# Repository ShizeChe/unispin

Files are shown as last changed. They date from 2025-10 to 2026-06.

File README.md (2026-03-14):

<h1 align="center">Unispin</h1>
<p align="center">A unified quantum control platform for quantum dot spin qubits</p>

<p align="center">
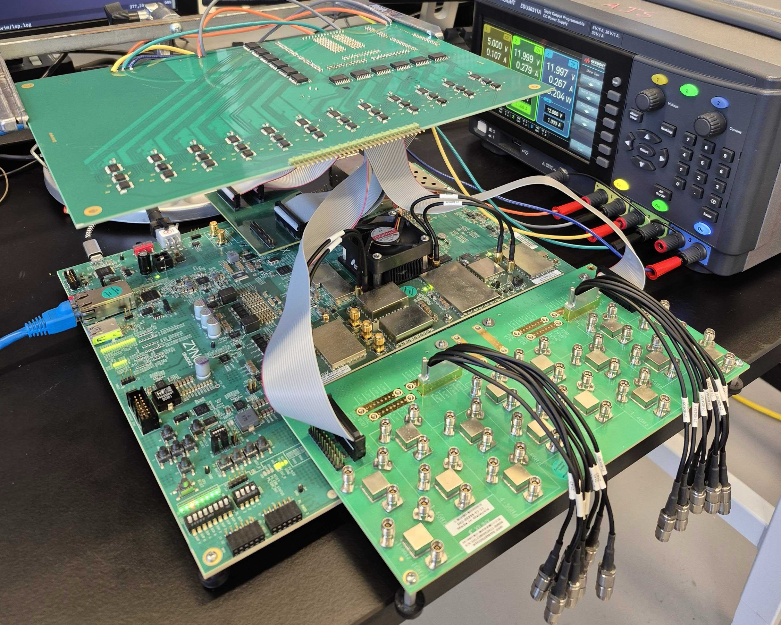
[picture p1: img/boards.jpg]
boards
 
</p>

Overview
========
Unispin is a unified quantum control platform designed specifically for quantum dot spin qubits. Its goal is to reduce control stack complexity and cost while improving performance by integrating all the requried control resources onto a single FPGA. With the two custom PCBs (FMC breakout board and low-noise DAC board), the current configuration has:

* 24x bias DC channels (AD5791BRUZ)
* 6x RF IQ pairs for further analog upconversion
* 2x singled-ended RF channels and 2x ADC channels for lockin-in measurement
* 2x singled-ended fast DC channels

Each signal and measurement channel has its own dedicated, fully-pipelined control core. Each core can be programmed to iteratively executes a sequence of custom assembly instructions with cycle-precise timing. The annotated pulse experiment assembly program and waveform below demonstrates this execution model.

```text
.program rf0                 # program for RF channel 0
.fnco 10MHz                  # NCO is 10MHz
.repeat 100                  # repeats 100 times
    idl t=19us (arm)         # idle for 19us
    ply phs=0 t=12ns (t+8ns) # play the NCO tone for 12ns (increment the pulse duration by 8ns every iteration)
    idl t=12us               # idle for 12us

.program dc0                 # program for DC channel 0
.repeat 100                  # this program repeats 100 times
    lvl v=0 t=2us (arm)      # output 0V for 2us
    lvl v=1 t=15us           # output 1V for 15us
    lvl v=2 t=2us            # output 2V for 2us
    idl t=12ns (t+8ns)       # idle for 12ns (increment the idle duration by 8ns every iteration)
    lvl v=1 t=10us           # output 1V for 10us
    lvl v=0 t=2us            # output 0V for 2us

.program li0                 # program for LI (lock-in) channel 0
.repeat 100                  # this program repeats 100 times
    idl t=19us (arm)         # idle for 19us
    idl t=12ns (t+8ns)       # idle for 12ns (increment the idle duration by 8ns every iteration)
    sam n=1000 t=10us        # sample 1000 samples spanning 10us
    idl t=2us                # idle for 2us

.launch rf0 dc0 li0          # launch RF channel 0, DC channel 0, LI channel 0 
```

<p align="center"> 
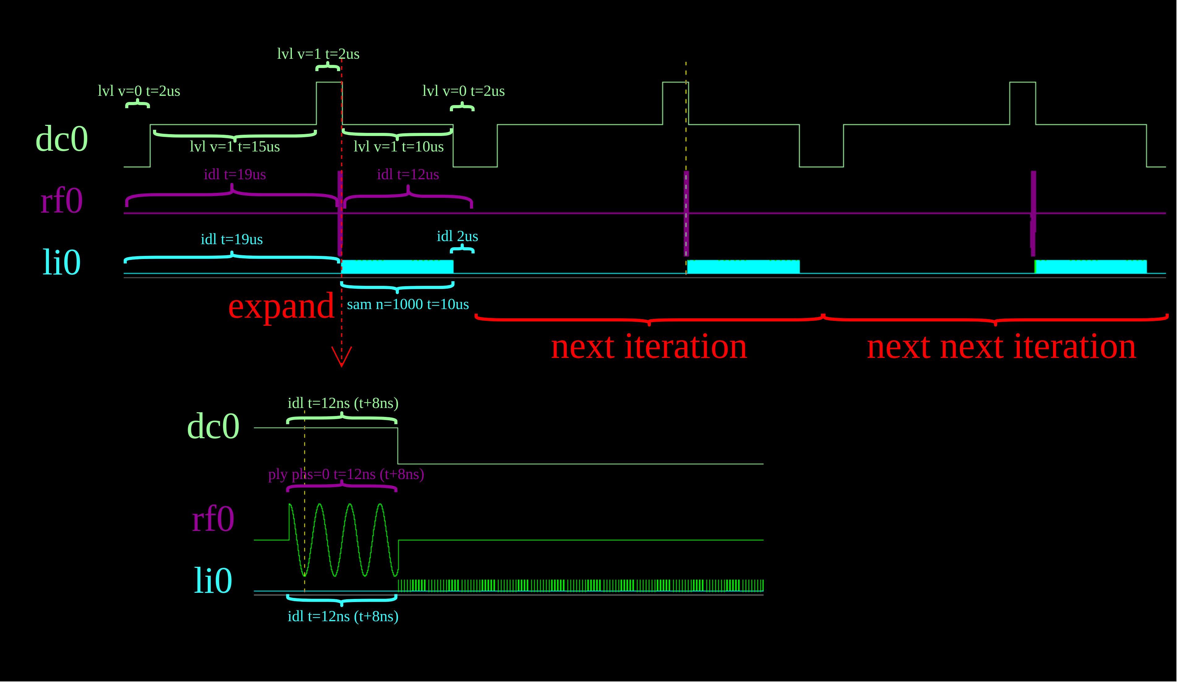
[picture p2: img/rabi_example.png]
rabi example
  
</p>

## Project Status
The project currently has three parts:
* RTL design, along with testbenches and some formal properties used for verification (under rtl)
* PCB design for the 24 bias DC channels, along with assembly instrctions (under pcb)
* Assembler for compiling and executing the custom assembly programs (under asm)

This project is currently under active development. The RTL design, PCB design, and assembler may continue to evolve as functionality is validated experimentally and the system is further refined. More detailed documentation and user guides will be added after real-device experiments.

## Building the rtl design project and bistream in Vivado
```bash
# clone repo
git clone "repo-url"

# go to the synthesis folder
cd unispin/rtl/synth

# build in vivado
vivado -script proj.tcl &
```
Note that proj.tcl only builds the project. Click generate bitstream in vivado to build the bitstream.

## Building the simulator (requires VCS+Verdi)
This simulator is our go-to method to visualize the full-system waveforms. It incorporates all the channels and cores and have simulated DAC and ADC modules for directly visualizing analog waveforms. It simulates AXI memory operations by accepting address and data through a socket interface, the received address and data are then written to the sequencer through its AXI interface.

Build the simulator. 
```bash
# assume we are in the top level of the cloned repo

# go to the rtl folder
cd unispin/rtl

# build the simulator (requires VCS)
make
```
This will create a simulator executable under rtl.

Execute the simulator in Verdi.
```bash
./simulator -gui -do sim/wv.tcl &
```

This will open up Verdi and load the waveforms. It will listen for connections and read address and data once running. Verdi can stop it at anytime to examine waveforms.

## Building the assembler
```bash
# assume we are in the top level of the cloned repo

# go to the asm folder
cd asm

# build the assmebler
make
```
This will create an executable named "squish" under asm.

Example assembling a .asm file and send to the simulator to visualize exection (with simulator running).
```bash
./squish -s -f ../exp/hahn_echo.asm
```

## Petalinux
A Petalinux OS can be built to interface with the cores in FPGA. os/petalinux-steps.md describes the steps we took to build a bootable image with an uio driver for each core.

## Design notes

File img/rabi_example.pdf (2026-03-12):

dc0

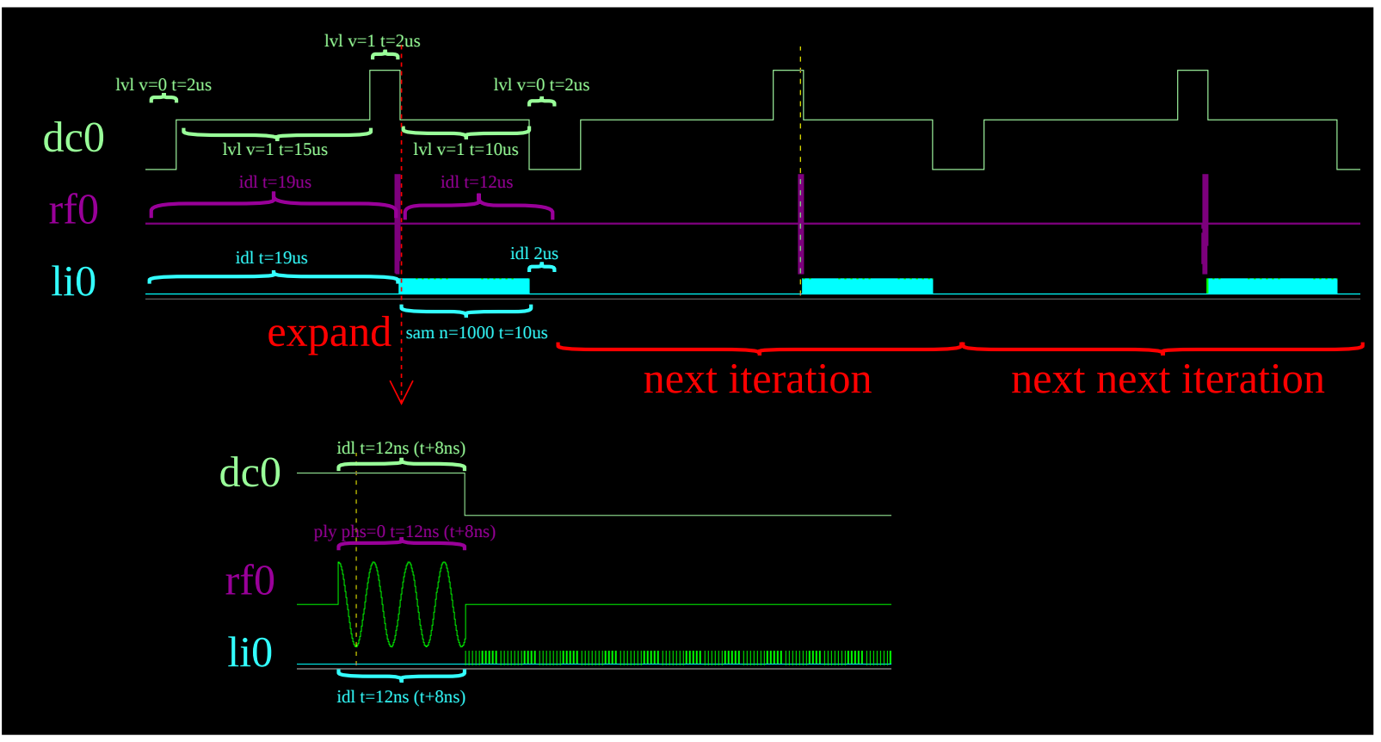
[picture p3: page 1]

rf0
li0

lvl v=0 t=2us

lvl v=1 t=15us

lvl v=1 t=2us

lvl v=1 t=10us

lvl v=0 t=2us

# expand

dc0

rf0
li0
idl t=19us | idl t=12us

idl t=12ns (t+8ns)

ply phs=0 t=12ns (t+8ns)

idl t=12ns (t+8ns)

idl t=19us

sam n=1000 t=10us

idl 2us

# next iteration next next iteration

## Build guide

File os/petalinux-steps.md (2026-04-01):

1. Export xsa file from vivado
2. Use vitis to create a linux platform with the exported xsa file as input
3. Vitis will create a folder: [vitis platform dir]/hw/sdt, this folder will be used in 7. Inside this folder, there should be a pl.dtsi file, it will be used in 13
4. Source settings.sh in the directory where petalinux is installed
5. Download the bsp (board support package) from the petalinux download page from xilinx
6. Run "petalinux-create -t project -s /path/to/bsp" to create a petalinux project directory based on the bsp
7. Run "petalinux-config --get-hw-description /path/to/[vitis platform dir]/hw/sdt" to do basic configuration
8. A terminal gui opens up, do the following:
   --DTG Settings->Kernel Bootargs->Uncheck "generate bookargs automatically"->
     Put "earlycon console=ttyPS0,115200 clk_ignore_unused uio_pdrv_genirq.of_id=generic-uio root=/dev/mmcblk0p2 rw rootwait" as the bootarg
   --FPGA Manager->Check FPGA Manager
   --Image Packaging Configurations->Root filesystem type->Select EXT4 (SD/eMMC/SATA/USB).
     Additionally, uncheck "Copy final images to tftpboot"
9. Run "petalinux-config -c kernel" to configure kernel
10. A terminal gui opens in a new shell window, check the following settings:
    --Device Drivers->Userspace I/O drivers->
      Change "Userspace I/O platform driver with generic IRQ handling" and 
      "Userspace platform driver with generic irq and dynamic memo" from "M" to fully selected
11. Run "petalinux-config -c rootfs" to configure root filesystem
12. A terminal gui opens up, check the following settings: (these are quality of life settings)
    --Image Features->check package-management
    --Filesystem Packages->base->opkg->check opkg
    --Go through the list and check everything you use for linux development
13. Modify [petalinux project dir]/project-spec/meta-user/recipes-bsp/device-tree/files/system-user.dtsi, do the following:
    --There should be "/ {}" prepared for you to override existing device tree setups
    --In pl.dtsi, you should recognize the blocks for your axi ips in pl
    --Copy the text that starts with "ambda_pl" in pl.dtsi to system-user.dtsi, put it into the "/ {}": "/ {'amba_pl...'}" 
    --Change the compatible="[place holder for driver]" in your axi ips to compatible="generic-uio"
    --Add 
    "&{/axi/mmc@ff170000} {
        status = "okay";
        disable-wp;
    };"
    below "/ {'amba_pl...}"
14. Run "petalinux-build" to build
15. Run "petalinux-package --boot --fsbl ./images/linux/zynqmp_fsbl.elf --fpga ./images/linux/system.bit --u-boot" to package
16. Run '''petalinux-package --wic --bootfiles "BOOT.BIN image.ub system.dtb boot.scr" \
           --rootfs-file ./images/linux/rootfs.tar.gz''' to build the sd card image
17. You should see [petalinux dir]/images/linux/petalinux-sdimage.wic, dd it to your sd card
18. After the kernel boots, go check /sys/class/uio/uio?/maps/map0/{name,addr}, 
    cat them and you should see your ip name and memory mapped addresses
19. If pl is not programmed, run "sudo fpgautil -b [bitstream] -f Full" to program pl
19. Use devmem to try read/write your ip

Useful posts:
https://www.hackster.io/engrinam0077/zcu104-mpsoc-development-petalinux-2024-2-basic-tutorial-c82b8d
https://www.reddit.com/r/FPGA/comments/1mgmbyh/start_to_finish_a_plps_design_guide_for_zynq/

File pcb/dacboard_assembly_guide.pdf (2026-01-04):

# DAC board assembly guide

Board front

DAC section (DAC set x12)

DAC set

Power section
FPGA IO section

Isolator section (Isolator set x6)

Isolator section (Isolator set x6

Isolator
set Isolator
set

lgclev def

Board back

FPGA IO section

DAC section (DAC set x12)

DAC set

Isolator section (Isolator set x6)

Isolator
set

Isolator section (Isolator set x6

Isolator

set

Power

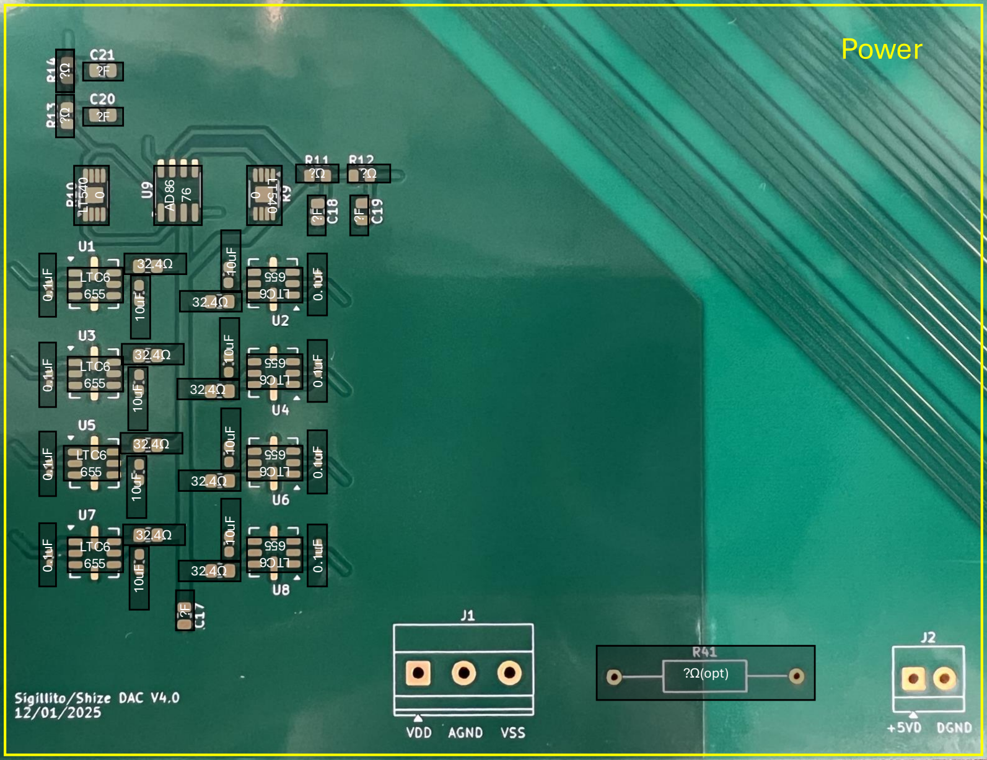
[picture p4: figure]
LTC6 655; 32.4Ω ¹⁰uF; ?Ω(opt); Power
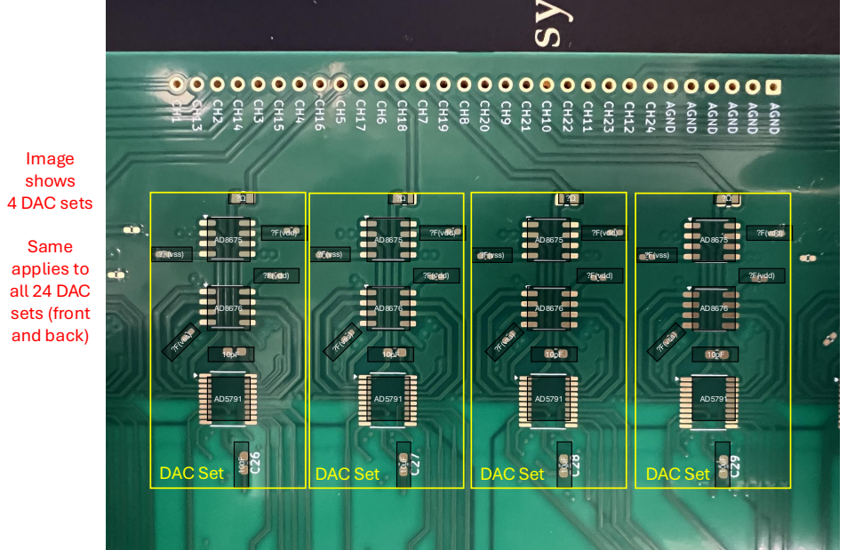
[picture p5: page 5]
?F(vss); ?F(vdd); DAC Set; Image shows 4 DAC sets; Same applies to all 24 DAC sets (front and back)

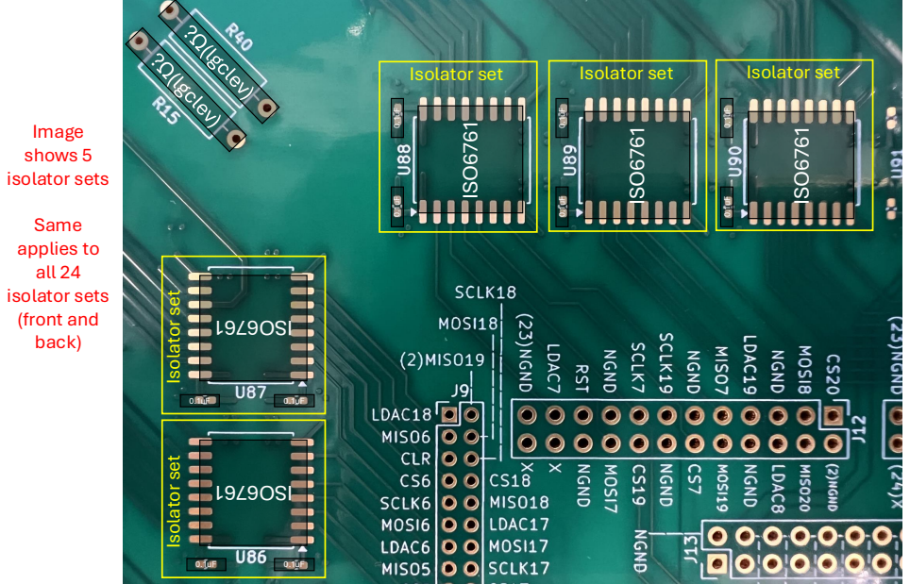
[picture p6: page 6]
ISO6761; Isolator set; Image shows 5 isolator sets; Same applies to all 24 isolator sets (front and back)

Isolator set

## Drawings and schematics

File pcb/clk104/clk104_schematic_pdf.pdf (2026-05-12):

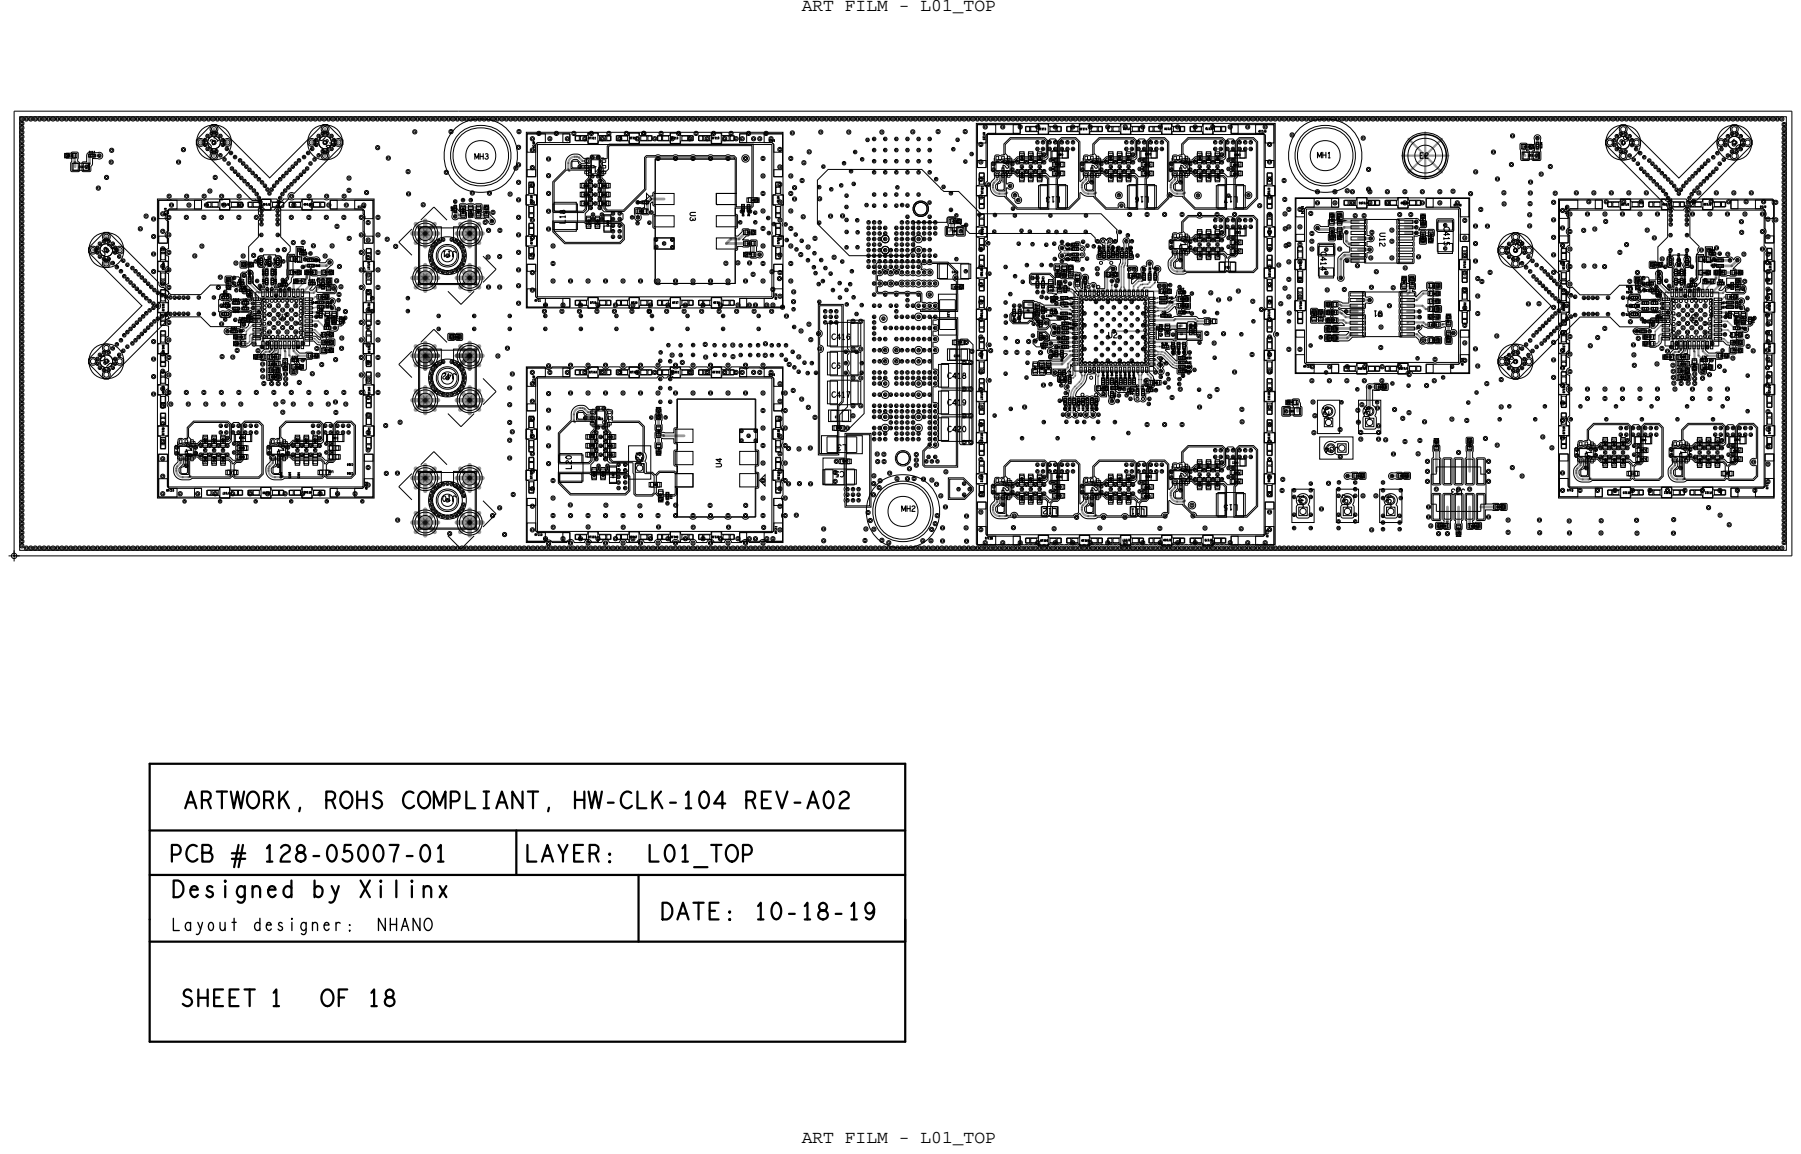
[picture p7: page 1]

ARTWORK, ROHS COMPLIANT, HW-CLK-104 REV-A02

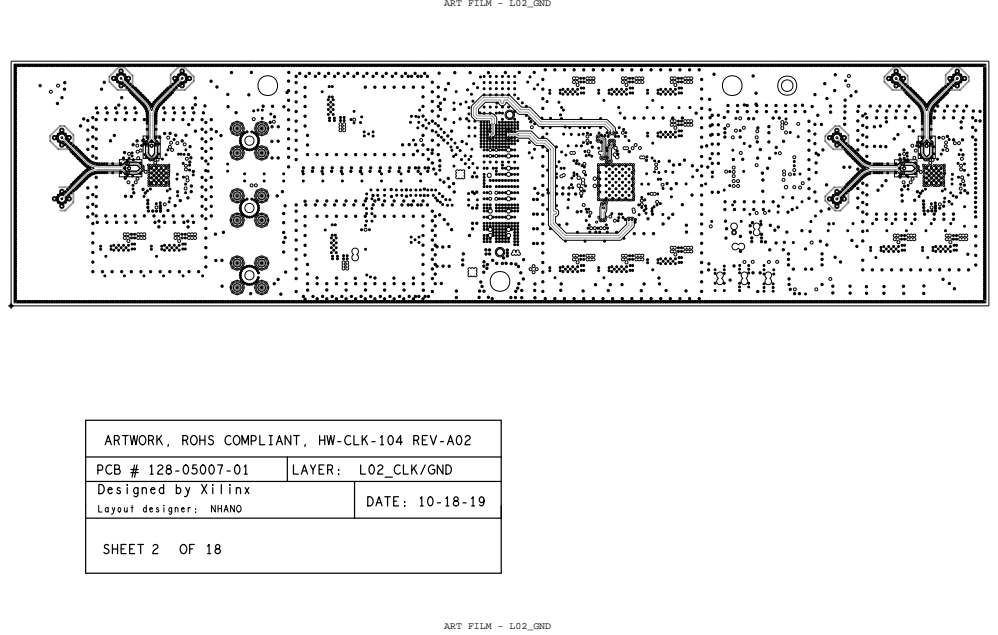
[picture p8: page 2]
ART FILM - L02_GND; DATE: 10-18-19; LAYER: L02_CLK/GND; NHANO; SHEET

ARTWORK, ROHS COMPLIANT, HW-CLK-104 REV-A02

PCB # 128-05007-01
Designed by Xilinx
Layout designer:

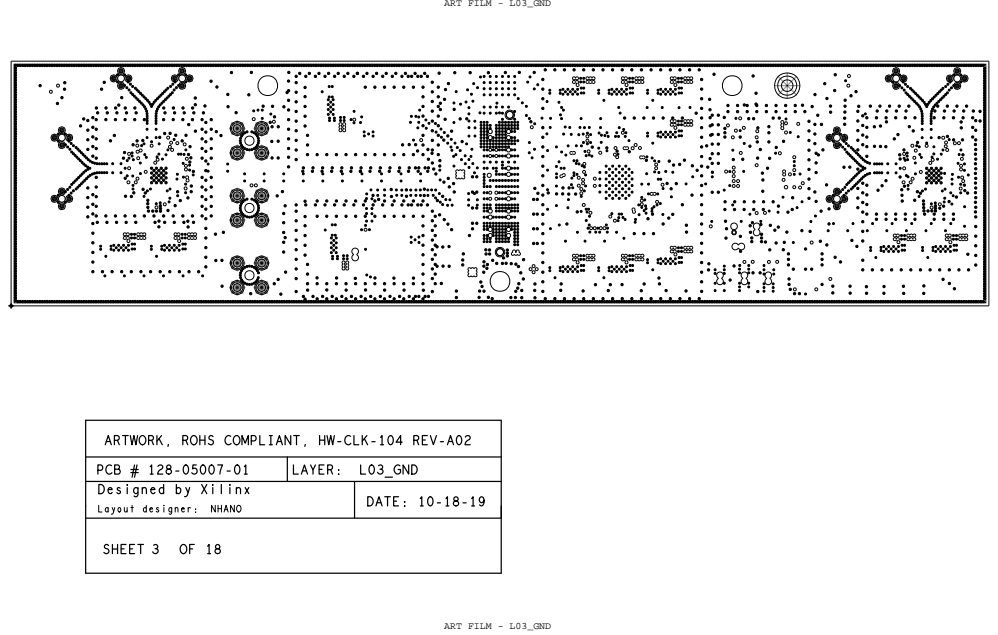
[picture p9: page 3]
ART FILM - L03_GND; DATE: 10-18-19; LAYER: L03_GND; NHANO; SHEET

ARTWORK, ROHS COMPLIANT, HW-CLK-104 REV-A02

PCB # 128-05007-01
Designed by Xilinx
Layout designer:

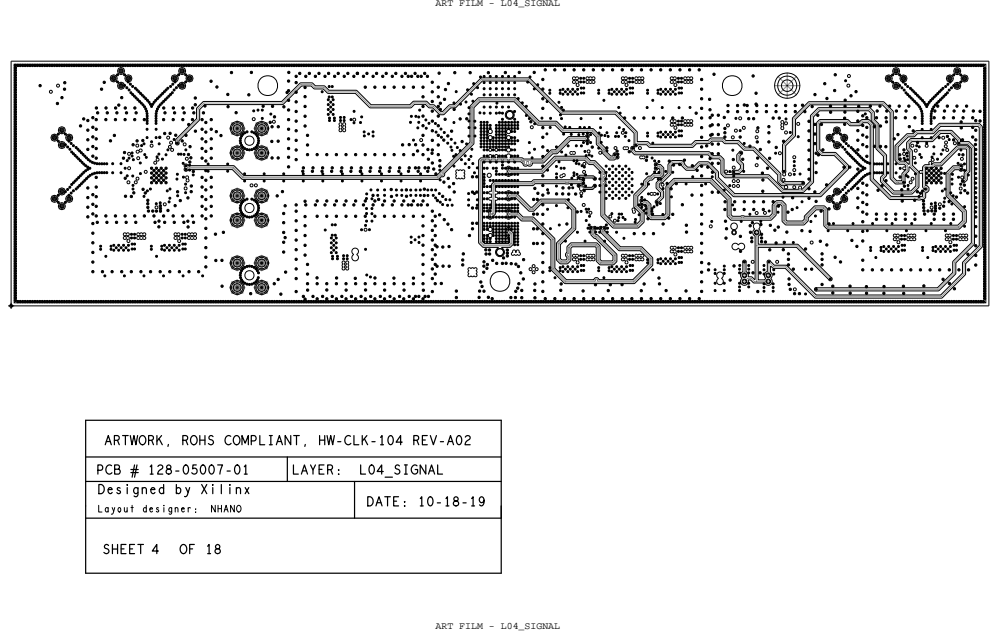
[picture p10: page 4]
ART FILM - L04_SIGNAL; DATE: 10-18-19; LAYER: L04_SIGNAL; NHANO; SHEET

ARTWORK, ROHS COMPLIANT, HW-CLK-104 REV-A02

PCB # 128-05007-01
Designed by Xilinx
Layout designer:

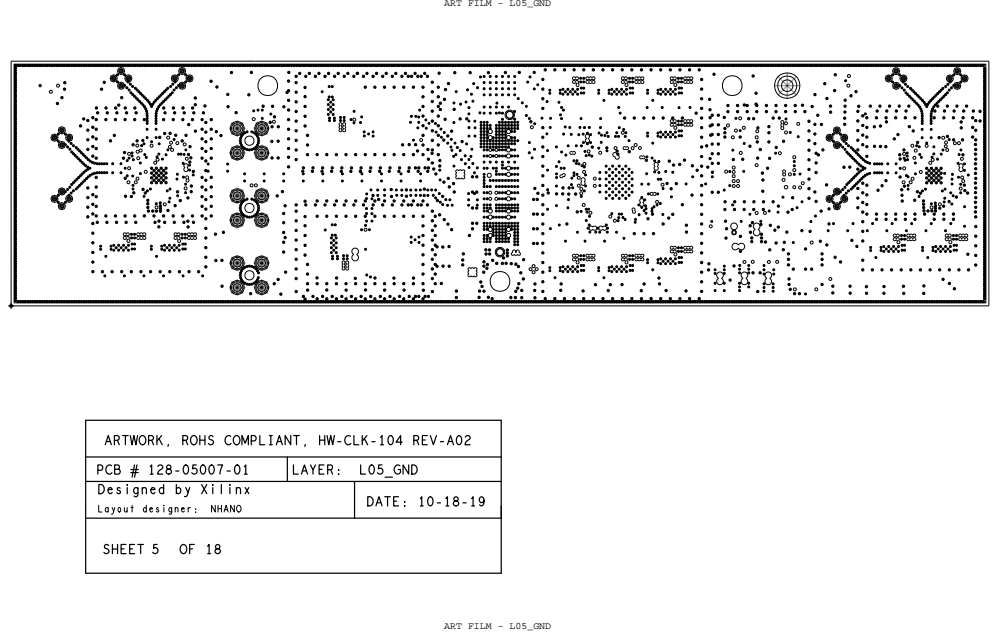
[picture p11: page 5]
ART FILM - L05_GND; DATE: 10-18-19; LAYER: L05_GND; NHANO; SHEET

ARTWORK, ROHS COMPLIANT, HW-CLK-104 REV-A02

PCB # 128-05007-01
Designed by Xilinx
Layout designer:

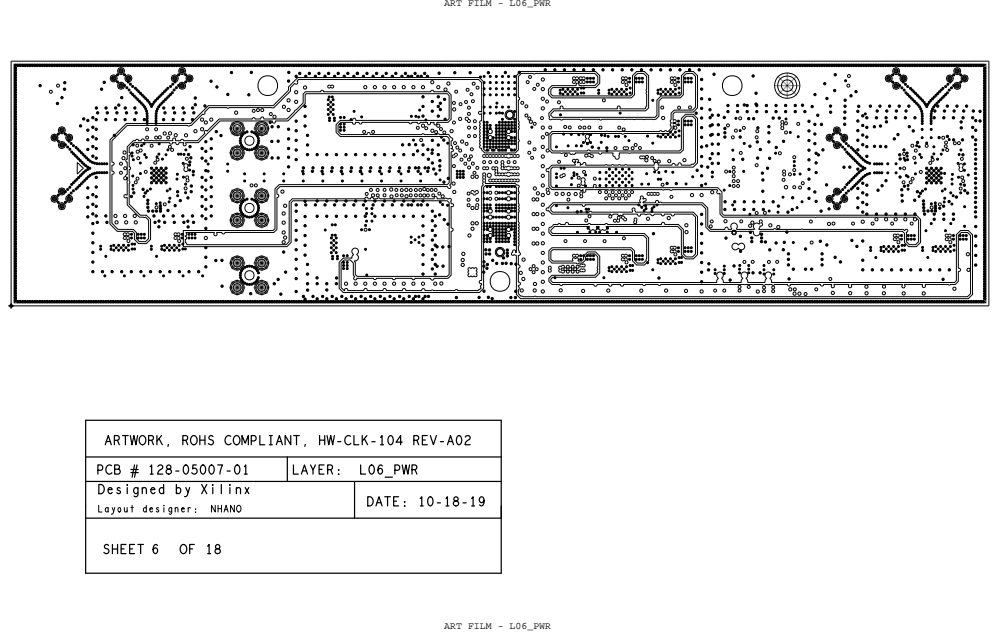
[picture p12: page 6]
ART FILM - L06_PWR; DATE: 10-18-19; LAYER: L06_PWR; NHANO; SHEET

ARTWORK, ROHS COMPLIANT, HW-CLK-104 REV-A02

PCB # 128-05007-01
Designed by Xilinx
Layout designer:

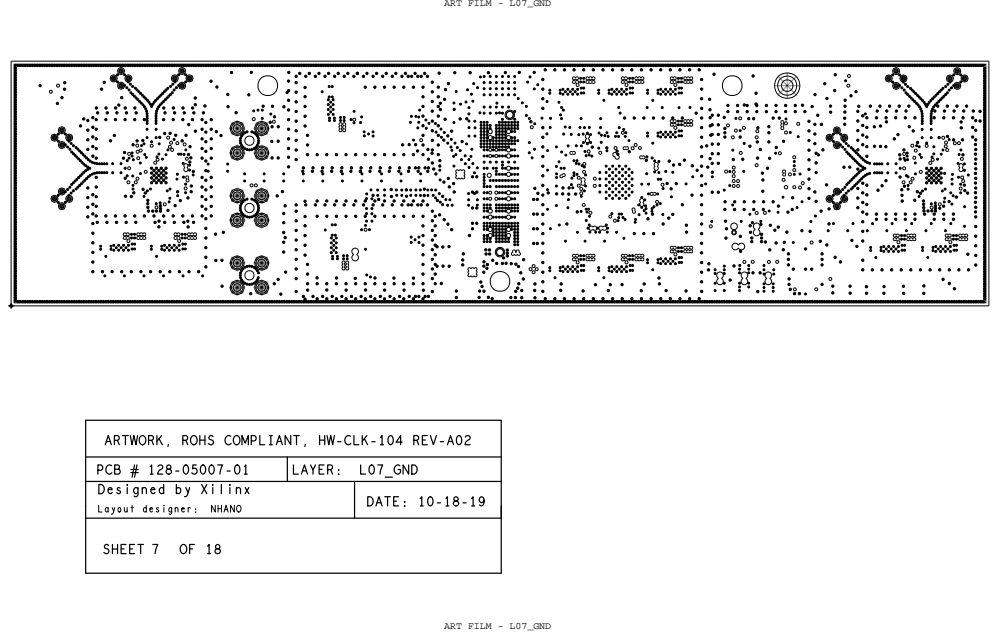
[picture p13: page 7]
ART FILM - L07_GND; DATE: 10-18-19; LAYER: L07_GND; NHANO; SHEET

ARTWORK, ROHS COMPLIANT, HW-CLK-104 REV-A02

PCB # 128-05007-01
Designed by Xilinx
Layout designer:

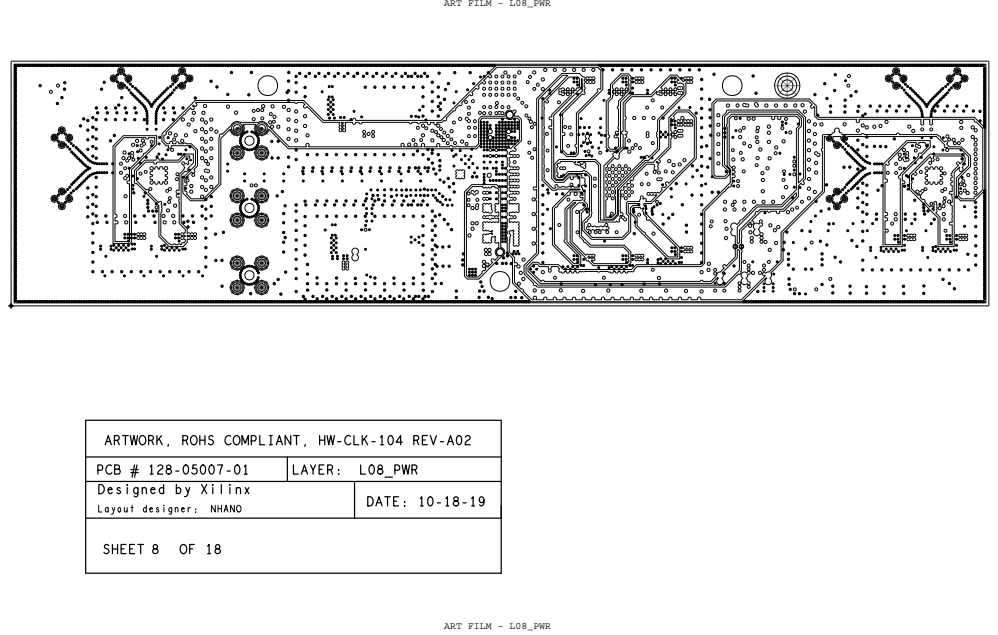
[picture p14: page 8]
ART FILM - L08_PWR; DATE: 10-18-19; LAYER: L08_PWR; NHANO; SHEET

ARTWORK, ROHS COMPLIANT, HW-CLK-104 REV-A02

PCB # 128-05007-01
Designed by Xilinx
Layout designer:

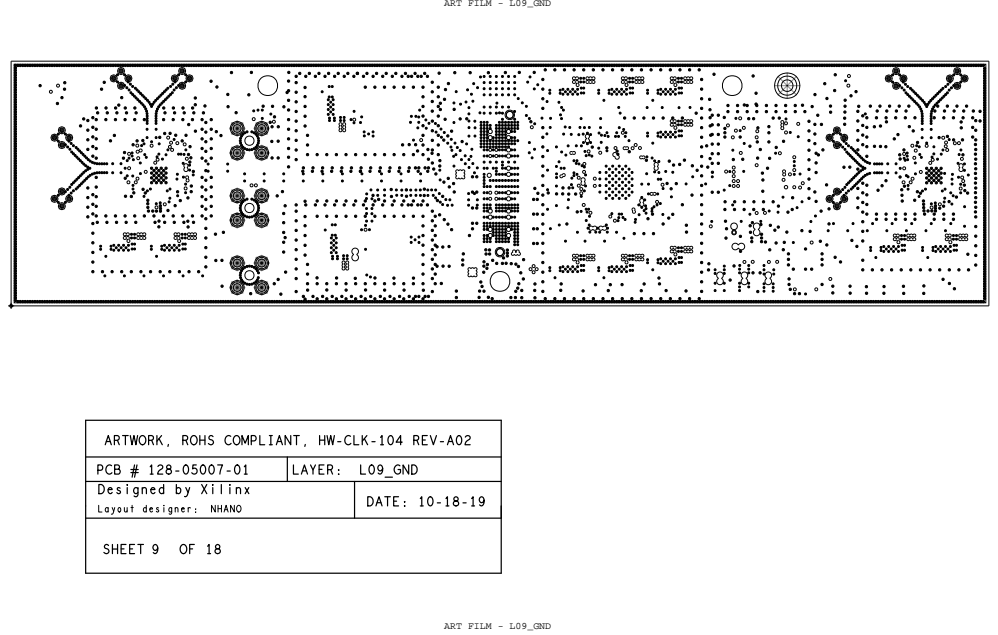
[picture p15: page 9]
ART FILM - L09_GND; DATE: 10-18-19; LAYER: L09_GND; NHANO; SHEET

ARTWORK, ROHS COMPLIANT, HW-CLK-104 REV-A02

PCB # 128-05007-01
Designed by Xilinx
Layout designer:

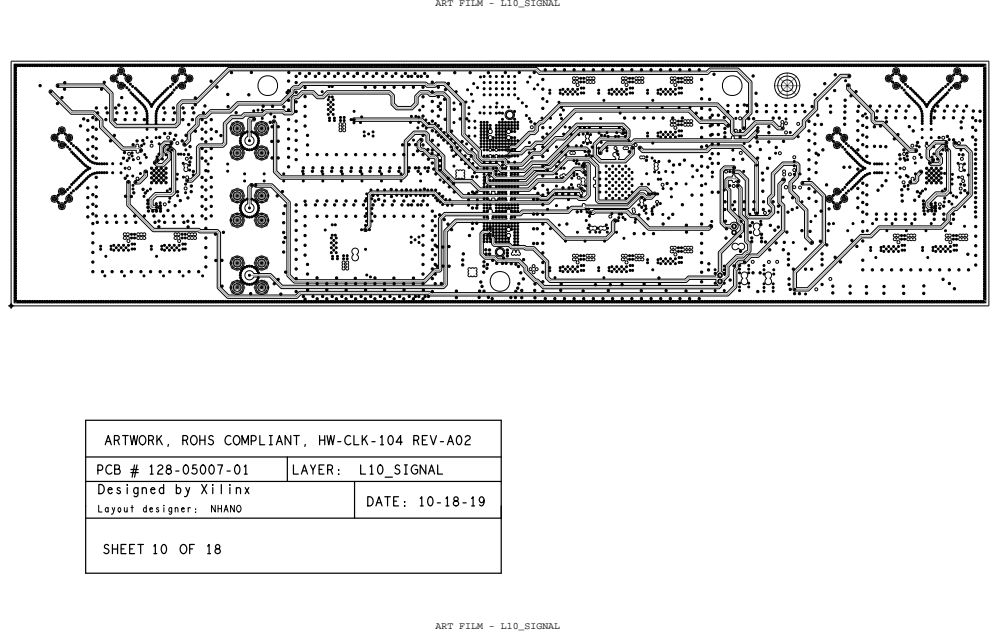
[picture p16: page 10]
ART FILM - L10_SIGNAL; DATE: 10-18-19; LAYER: L10_SIGNAL; NHANO; SHEET

ARTWORK, ROHS COMPLIANT, HW-CLK-104 REV-A02

PCB # 128-05007-01
Designed by Xilinx
Layout designer:

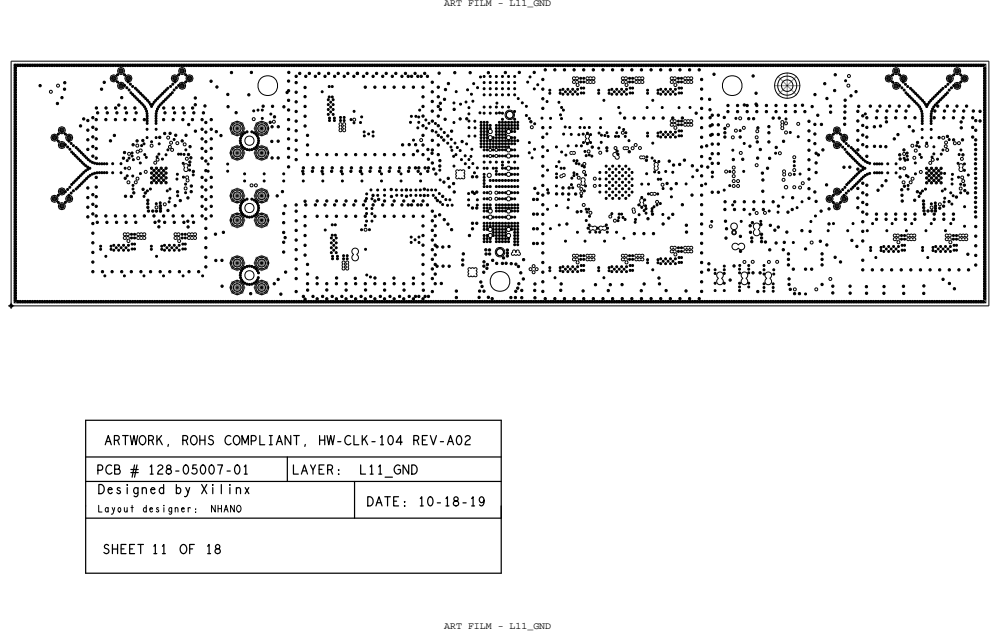
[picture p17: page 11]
ART FILM - L11_GND; DATE: 10-18-19; LAYER: L11_GND; NHANO; SHEET

ARTWORK, ROHS COMPLIANT, HW-CLK-104 REV-A02

PCB # 128-05007-01
Designed by Xilinx
Layout designer:

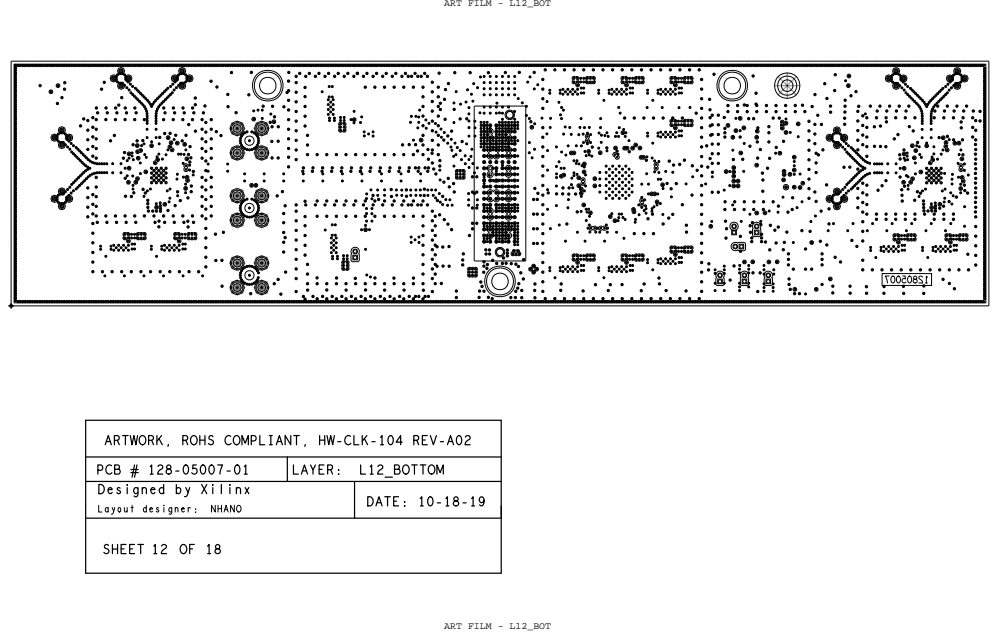
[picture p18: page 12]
ART FILM - L12_BOT; DATE: 10-18-19; LAYER: L12_BOTTOM; NHANO; SHEET

ARTWORK, ROHS COMPLIANT, HW-CLK-104 REV-A02

PCB # 128-05007-01
Designed by Xilinx
Layout designer:

ART FILM - MASK_BOTTOM; ARTWORK, ROHS COMPLIANT,; HW-CLK-104 REV-A02; Designed; by Xilinx; SHEET

PCB # 128-05007-01 | LAYER: MASK_BOTTOM

Layout designer: NHANO | DATE: 10-18-19

ART FILM - MASK_TOP; DATE: 10-18-19; LAYER: MASK_TOP; NHANO; SHEET

ARTWORK, ROHS COMPLIANT, HW-CLK-104 REV-A02

PCB # 128-05007-01
Designed by Xilinx
Layout designer:

ART FILM - PASTE_BOT; ARTWORK, ROHS COMPLIANT,; HW-CLK-104 REV-A02; Designed; by Xilinx; SHEET

PCB # 128-05007-01 | LAYER: PASTE_BOT

Layout designer: NHANO | DATE: 10-18-19

ART FILM - PASTE_TOP; DATE: 10-18-19; LAYER: PASTE_TOP; NHANO; SHEET

ARTWORK, ROHS COMPLIANT, HW-CLK-104 REV-A02

PCB # 128-05007-01
Designed by Xilinx
Layout designer:

ART FILM - SILK_BOT; ARTWORK, ROHS COMPLIANT,; HW-CLK-104 REV-A02; Designed; by Xilinx; SHEET

PCB # 128-05007-01 | LAYER: SILK BOTTOM

Layout designer: NHANO | DATE: 10-18-19

1C134 U19 18


PCB # 128-05007-01

Layout designer: NHANO | DATE: 10-18-19

1

# QTY


DRILL CHART: TOP to L02_CLK
ALL UNITS ARE IN MILS

NOTES:
2. BOARD SHALL MEET THE INSPECTION CRITERIA
OF IPC-A-600,CLASS 2,CURRENT REVISION.
4. WEIGHT OF ALL COPPER LAYERS SHALL NOT BE LESS
0.5 OZ. PER SQUARE FOOT.
5. IMPEDANCE REQUIREMENTS REFER TO CHART. TOLERANCE +/-10% EXCEPT AS NOTED.
6. APPLY SOLDER MASK OVER BARE COPPER(SMBOC) IAW
IPC-SM-840,BOTH SIDES,USING LPI,COLOR GREEN
8. SILKSCREEN TOP SIDE/BOTH SIDES WITH NON-CONDUCTIVE EPOXY BASED INK.
COLOR SHALL BE WHITE A CONTRASTING INK WITH RESPECT TO SOLDER MASK COLOR.
DISTORTION OF SILKSCREEN IS ACCEPTABLE OVER TRACES.
EPOXY INK ON PLATED LANDS IS NOT ACCEPTABLE.
9. VENDOR LOGO AND DATE CODE TO BE MAKED FAR SIDE.
MAXIMUM HEIGHT .12 INCHES.
10. 100% ELECTRICAL TEST REQUIRED FOR CONTINUITY. BOARD SHALL HAVE A
UL RATING OF 94V-0. UL SYMBOL AND RATING SHAL BE MARKED FARSIDE.
11. REMOVE ALL UNUSED PADS FROM INTERNAL LAYERS.
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


















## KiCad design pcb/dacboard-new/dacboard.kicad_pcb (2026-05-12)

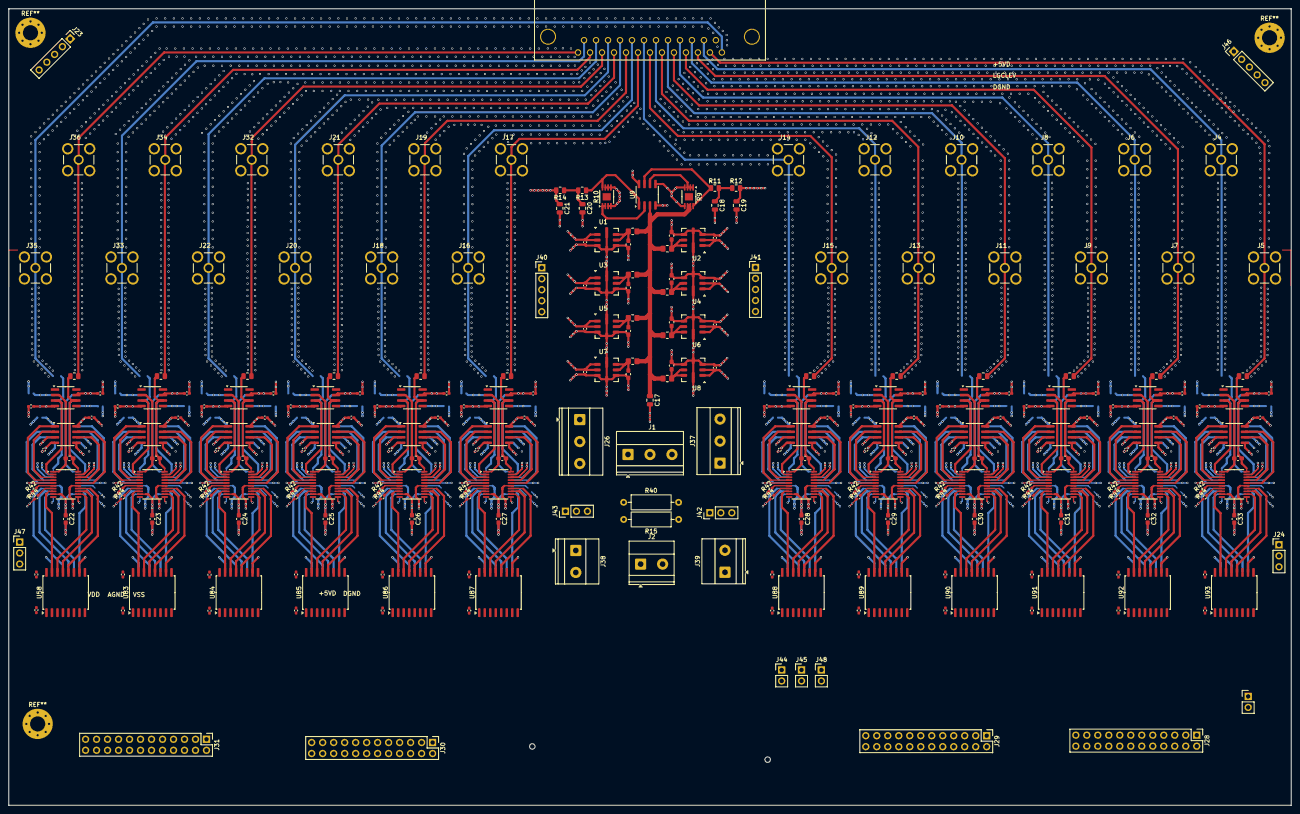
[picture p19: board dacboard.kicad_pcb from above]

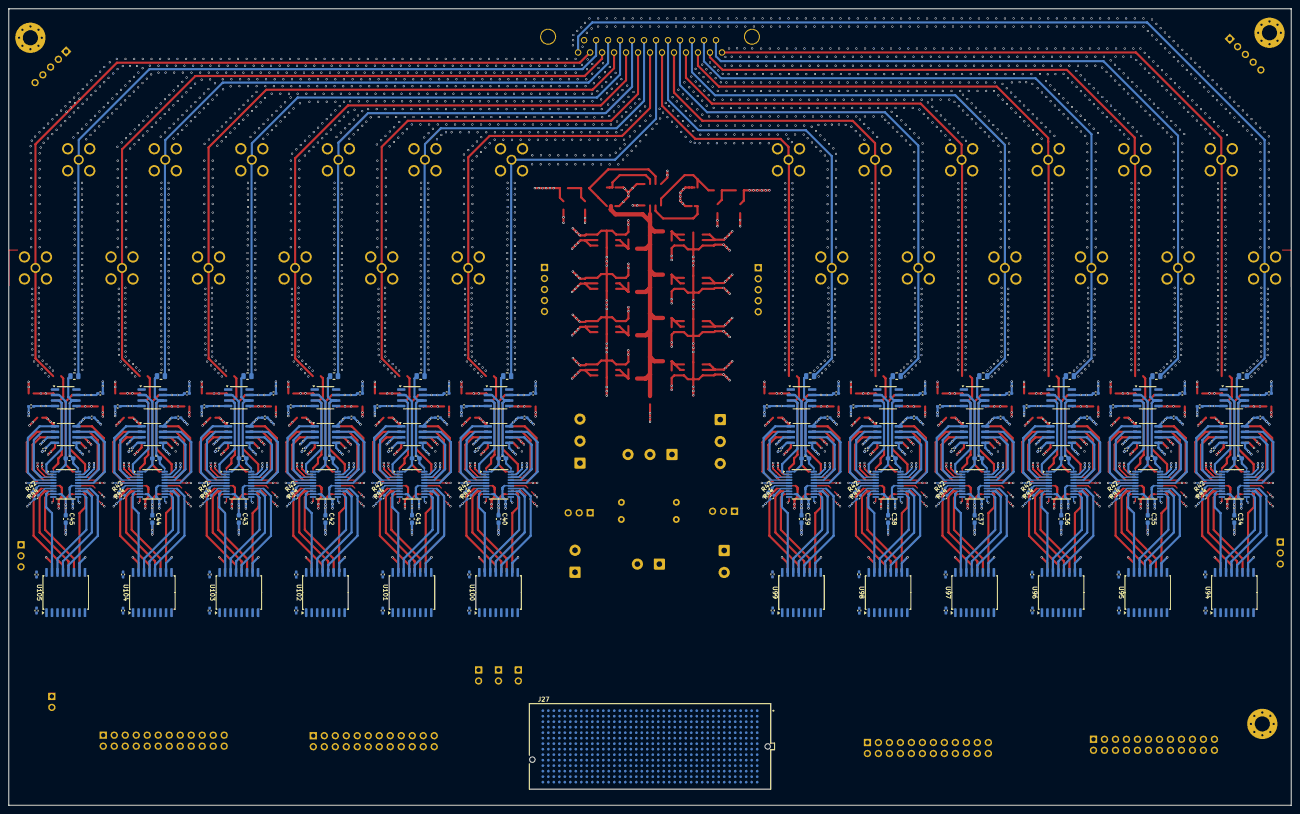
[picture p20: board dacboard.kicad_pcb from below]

Board: 16 copper layers, 296.3 x 184.0 mm, 454 parts (181 on the bottom side), 340 nets.

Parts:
C1, C3, C5, C7, C9, C11, C13, C15, C72, C73, C74, C75, C76, C77, C78, C79, C80, C81, C82, C83, C84, C85, C86, C87, C88, C89, C90, C91, C92, C93, C94, C95, C96, C97, C98, C99, C100, C101, C102, C103, C104, C105, C106, C107, C108, C109, C110, C111, C112, C113, C114, C115, C116, C117, C118, C119: 0.1uF; C_0402_1005Metric_Pad0.74x0.62mm_HandSolder
C2, C4, C6, C8, C10, C12, C14, C16, C22, C23, C24, C25, C26, C27, C28, C29, C30, C31, C32, C33, C34, C35, C36, C37, C38, C39, C40, C41, C42, C43, C44, C45: 10uF; C_0603_1608Metric_Pad1.08x0.95mm_HandSolder
C17, C18, C19, C20, C21: C; C_0805_2012Metric
C46, C71, C120, C121, C122, C123, C124, C125, C126, C127, C128, C129, C130, C131, C132, C133, C134, C135, C136, C137, C138, C139, C140, C141, C142, C143, C144, C145, C146, C147, C148, C149, C150, C151, C152, C153, C154, C155, C156, C157, C158, C159, C160, C161, C162, C163, C164, C165, C166, C167, C168, C169, C170, C171, C172, C173, C174, C175, C176, C177, C178, C179, C180, C181, C182, C183, C184, C185, C186, C187, C188, C189, C190, C191, C192, C193, C194, C195, C196, C197, C198, C199, C200, C201, C202, C203, C204, C205, C206, C207, C208, C209, C210, C211, C212, C213: C; C_0402_1005Metric_Pad0.74x0.62mm_HandSolder
C47, C48, C49, C50, C51, C52, C53, C54, C55, C56, C57, C58, C59, C60, C61, C62, C63, C64, C65, C66, C67, C68, C69, C70: 10pF; C_0603_1608Metric_Pad1.08x0.95mm_HandSolder
J1, J26, J37: Screw_Terminal_01x03; TerminalBlock_Phoenix_MKDS-1,5-3-5.08_1x03_P5.08mm_Horizont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
J2, J38, J39: Screw_Terminal_01x02; TerminalBlock_Phoenix_MKDS-1,5-2-5.08_1x02_P5.08mm_Horizont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
J3: DLS3XS6AK44X; CONN_DLS3XS6AK44X_CEC
J4, J5, J6, J7, J8, J9, J10, J11, J12, J13, J14, J15, J16, J17, J18, J19, J20, J21, J22, J32, J33, J34, J35, J36: RFPC-SMA28-F; GRADCONN_RFPC-SMA28-F
J23, J40, J41, J46: Conn_01x05; PinHeader_1x05_P2.54mm_Vertical
J24, J42, J43, J47: Conn_01x03; PinHeader_1x03_P2.54mm_Vertical
J25, J44, J45, J48: Conn_01x02; PinHeader_1x02_P2.54mm_Vertical
J27: ASP-184330-01; SAMTEC_ASP-184330-01
J28, J29, J30, J31: Conn_02x12_Odd_Even; PinHeader_2x12_P2.54mm_Vertical
R1, R2, R3, R4, R5, R6, R7, R8: 32.4ohm; R_0805_2012Metric_Pad1.20x1.40mm_HandSolder
R9, R10: LT5400BCMS8E-7_PBF; MSOP-8-1EP_3x3mm_P0.65mm_EP1.68x1.88mm
R11, R12, R13, R14, R16, R17, R18, R19, R20, R21, R22, R23, R24, R25, R26, R27, R28, R29, R30, R31, R32, R33, R34, R35, R36, R37, R38, R39: R_US; R_0805_2012Metric
R15, R40: R_US; R_Axial_DIN0309_L9.0mm_D3.2mm_P12.70mm_Horizontal
R42, R42#2, R42#3, R42#4, R42#5, R42#6, R42#7, R42#8, R42#9, R42#10, R42#11, R42#12, R42#13, R42#14, R42#15, R42#16, R42#17, R42#18, R42#19, R42#20, R42#21, R42#22, R42#23, R42#24, R44, R44#2, R44#3, R44#4, R44#5, R44#6, R44#7, R44#8, R44#9, R44#10, R44#11, R44#12, R44#13, R44#14, R44#15, R44#16, R44#17, R44#18, R44#19, R44#20, R44#21, R44#22, R44#23, R44#24: 10K; R_0402_1005Metric_Pad0.72x0.64mm_HandSolder
U1, U2, U3, U4, U5, U6, U7, U8: LTC6655CHMS8-2.5_PBF; Analog_LCC-8_5x5mm_P1.27mm
U9, U11, U12, U14, U16, U18, U20, U22, U23, U24, U25, U30, U31, U34, U35, U36, U37, U42, U43, U46, U47, U48, U49, U54, U55: AD8676xR; SOIC-8_3.9x4.9mm_P1.27mm
U10, U13, U15, U17, U19, U21, U26, U27, U28, U29, U32, U33, U38, U39, U40, U41, U44, U45, U50, U51, U52, U53, U56, U57: AD5791BRUZ; TSSOP-20_4.4x6.5mm_P0.65mm
U58, U83, U84, U85, U86, U87, U88, U89, U90, U91, U92, U93, U94, U95, U96, U97, U98, U99, U100, U101, U102, U103, U104, U105: ISO6761FQDWRQ1; SOIC-16W_7.5x10.3mm_P1.27mm
U59, U60, U61, U62, U63, U64, U65, U66, U67, U68, U69, U70, U71, U72, U73, U74, U75, U76, U77, U78, U79, U80, U81, U82: AD8675ARZ; SOIC-8_3.9x4.9mm_P1.27mm

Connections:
+5VD: C22.1, C23.1, C24.1, C25.1, C26.1, C27.1, C28.1, C29.1, C30.1, C31.1, C32.1, C33.1, C34.1, C35.1, C36.1, C37.1, C38.1, C39.1, C40.1, C41.1, C42.1, C43.1, C44.1, C45.1, C73.2, C75.2, C77.2, C81.2, C82.2, C83.2, C87.2, C88.2, C89.2, C93.2, C94.2, C95.2, C99.2, C100.2, C101.2, C105.2, C106.2, C107.2, C111.2, C112.2, C113.2, C117.2, C118.2, C119.2, J2.1, J24.1, J38.1, J39.1, J42.1, J43.1, J47.1, R15.1, R42.1, R42#2.1, R42#3.1, R42#4.1, R42#5.1, R42#6.1, R42#7.1, R42#8.1, R42#9.1, R42#10.1, R42#11.1, R42#12.1, R42#13.1, R42#14.1, R42#15.1, R42#16.1, R42#17.1, R42#18.1, R42#19.1, R42#20.1, R42#21.1, R42#22.1, R42#23.1, R42#24.1, R44.1, R44#2.1, R44#3.1, R44#4.1, R44#5.1, R44#6.1, R44#7.1, R44#8.1, R44#9.1, R44#10.1, R44#11.1, R44#12.1, R44#13.1, R44#14.1, R44#15.1, R44#16.1, R44#17.1, R44#18.1, R44#19.1, R44#20.1, R44#21.1, R44#22.1, R44#23.1, R44#24.1, U10.9 (VCC), U13.9 (VCC), U15.9 (VCC), U17.9 (VCC), U19.9 (VCC), U21.9 (VCC), U26.9 (VCC), U27.9 (VCC), U28.9 (VCC), U29.9 (VCC), U32.9 (VCC), U33.9 (VCC), U38.9 (VCC), U39.9 (VCC), U40.9 (VCC), U41.9 (VCC), U44.9 (VCC), U45.9 (VCC), U50.9 (VCC), U51.9 (VCC), U52.9 (VCC), U53.9 (VCC), U56.9 (VCC), U57.9 (VCC), U58.16 (VCC2), U83.16 (VCC2), U84.16 (VCC2), U85.16 (VCC2), U86.16 (VCC2), U87.16 (VCC2), U88.16 (VCC2), U89.16 (VCC2), U90.16 (VCC2), U91.16 (VCC2), U92.16 (VCC2), U93.16 (VCC2), U94.16 (VCC2), U95.16 (VCC2), U96.16 (VCC2), U97.16 (VCC2), U98.16 (VCC2), U99.16 (VCC2), U100.16 (VCC2), U101.16 (VCC2), U102.16 (VCC2), U103.16 (VCC2), U104.16 (VCC2), U105.16 (VCC2)
AGND: C1.2, C2.2, C3.2, C4.2, C5.2, C6.2, C7.2, C8.2, C9.2, C10.2, C11.2, C12.2, C13.2, C14.2, C15.2, C16.2, C17.2, C18.2, C19.2, C20.2, C21.2, C46.2, C71.2, C120.2, C121.2, C122.2, C123.2, C124.2, C125.2, C126.2, C127.2, C128.2, C129.2, C130.2, C131.2, C132.2, C133.2, C134.2, C135.2, C136.2, C137.2, C138.2, C139.2, C140.2, C141.2, C142.2, C143.2, C144.2, C145.2, C146.2, C147.2, C148.2, C149.2, C150.2, C151.2, C152.2, C153.2, C154.2, C155.2, C156.2, C157.2, C158.2, C159.2, C160.2, C161.2, C162.2, C163.2, C164.2, C165.2, C166.2, C167.2, C168.2, C169.2, C170.2, C171.2, C172.2, C173.2, C174.2, C175.2, C176.2, C177.2, C178.2, C179.2, C180.2, C181.2, C182.2, C183.2, C184.2, C185.2, C186.2, C187.2, C188.2, C189.2, C190.2, C191.2, C192.2, C193.2, C194.2, C195.2, C196.2, C197.2, C198.2, C199.2, C200.2, C201.2, C202.2, C203.2, C204.2, C205.2, C206.2, C207.2, C208.2, C209.2, C210.2, C211.2, C212.2, C213.2, J1.2, J4.G1, J4.G2, J4.G3, J4.G4, J5.G1, J5.G2, J5.G3, J5.G4, J6.G1, J6.G2, J6.G3, J6.G4, J7.G1, J7.G2, J7.G3, J7.G4, J8.G1, J8.G2, J8.G3, J8.G4, J9.G1, J9.G2, J9.G3, J9.G4, J10.G1, J10.G2, J10.G3, J10.G4, J11.G1, J11.G2, J11.G3, J11.G4, J12.G1, J12.G2, J12.G3, J12.G4, J13.G1, J13.G2, J13.G3, J13.G4, J14.G1, J14.G2, J14.G3, J14.G4, J15.G1, J15.G2, J15.G3, J15.G4, J16.G1, J16.G2, J16.G3, J16.G4, J17.G1, J17.G2, J17.G3, J17.G4, J18.G1, J18.G2, J18.G3, J18.G4, J19.G1, J19.G2, J19.G3, J19.G4, J20.G1, J20.G2, J20.G3, J20.G4, J21.G1, J21.G2, J21.G3, J21.G4, J22.G1, J22.G2, J22.G3, J22.G4, J23.2, J26.2, J32.G1, J32.G2, J32.G3, J32.G4, J33.G1, J33.G2, J33.G3, J33.G4, J34.G1, J34.G2, J34.G3, J34.G4, J35.G1, J35.G2, J35.G3, J35.G4, J36.G1, J36.G2, J36.G3, J36.G4, J37.2, J40.2, J41.2, J46.2, R9.4, R9.5, R10.3, R10.4, R10.5, R10.6, R10.7, U1.3 (GND), U1.4 (GND__1), U1.5 (GND__2), U1.8 (GND__3), U2.3 (GND), U2.4 (GND__1), U2.5 (GND__2), U2.8 (GND__3), U3.3 (GND), U3.4 (GND__1), U3.5 (GND__2), U3.8 (GND__3), U4.3 (GND), U4.4 (GND__1), U4.5 (GND__2), U4.8 (GND__3), U5.3 (GND), U5.4 (GND__1), U5.5 (GND__2), U5.8 (GND__3), U6.3 (GND), U6.4 (GND__1), U6.5 (GND__2), U6.8 (GND__3), U7.3 (GND), U7.4 (GND__1), U7.5 (GND__2), U7.8 (GND__3), U8.3 (GND), U8.4 (GND__1), U8.5 (GND__2), U8.8 (GND__3), U9.5 (+), U10.19 (AGND), U13.19 (AGND), U15.19 (AGND), U17.19 (AGND), U19.19 (AGND), U21.19 (AGND), U26.19 (AGND), U27.19 (AGND), U28.19 (AGND), U29.19 (AGND), U32.19 (AGND), U33.19 (AGND), U38.19 (AGND), U39.19 (AGND), U40.19 (AGND), U41.19 (AGND), U44.19 (AGND), U45.19 (AGND), U50.19 (AGND), U51.19 (AGND), U52.19 (AGND), U53.19 (AGND), U56.19 (AGND), U57.19 (AGND)
BUF1_VOUT: J3.1, J36.1, R16.2
BUF2_VOUT: J3.2, J34.1, R17.2
BUF3_VOUT: J3.3, J32.1, R18.2
BUF4_VOUT: J3.4, J21.1, R19.2
BUF5_VOUT: J3.5, J19.1, R20.2
BUF6_VOUT: J3.6, J17.1, R21.2
BUF7_VOUT: J3.7, J15.1, R22.2
BUF8_VOUT: J3.8, J13.1, R23.2
BUF9_VOUT: J3.9, J11.1, R24.2
BUF10_VOUT: J3.10, J9.1, R25.2
BUF11_VOUT: J3.11, J7.1, R26.2
BUF12_VOUT: J3.12, J5.1, R27.2
BUF13_VOUT: J3.13, J35.1, R28.2
BUF14_VOUT: J3.14, J33.1, R29.2
BUF15_VOUT: J3.15, J22.1, R30.2
BUF16_VOUT: J3.16, J20.1, R31.2
BUF17_VOUT: J3.17, J18.1, R32.2
BUF18_VOUT: J3.18, J16.1, R33.2
BUF19_VOUT: J3.19, J14.1, R34.2
BUF20_VOUT: J3.20, J12.1, R35.2
BUF21_VOUT: J3.21, J10.1, R36.2
BUF22_VOUT: J3.22, J8.1, R37.2
BUF23_VOUT: J3.23, J6.1, R38.2
BUF24_VOUT: J3.24, J4.1, R39.2
DAC1_INV: C47.1, U10.1 (INV), U59.2 (IN-)
DAC1_LDAC_N: U10.8 (*LDAC), U58.15 (OUTA)
DAC1_RFB: C47.2, R16.1, U10.20 (RFB), U59.6 (OUT)
DAC1_SCLK: U10.13 (SCLK), U58.13 (OUTC)
DAC1_SDIN: U10.12 (SDIN), U58.14 (OUTB)
DAC1_SDO: U10.11 (SDO), U58.10 (INF)
DAC1_SYNC_N: U10.14 (*SYNC), U58.12 (OUTD)
DAC1_VOUT: U10.2 (VOUT), U59.3 (IN+)
DAC2_INV: C48.1, U13.1 (INV), U60.2 (IN-)
DAC2_LDAC_N: U13.8 (*LDAC), U83.15 (OUTA)
DAC2_RFB: C48.2, R17.1, U13.20 (RFB), U60.6 (OUT)
DAC2_SCLK: U13.13 (SCLK), U83.13 (OUTC)
DAC2_SDIN: U13.12 (SDIN), U83.14 (OUTB)
DAC2_SDO: U13.11 (SDO), U83.10 (INF)
DAC2_SYNC_N: U13.14 (*SYNC), U83.12 (OUTD)
DAC2_VOUT: U13.2 (VOUT), U60.3 (IN+)
DAC3_INV: C49.1, U15.1 (INV), U61.2 (IN-)
DAC3_LDAC_N: U15.8 (*LDAC), U84.15 (OUTA)
DAC3_RFB: C49.2, R18.1, U15.20 (RFB), U61.6 (OUT)
DAC3_SCLK: U15.13 (SCLK), U84.13 (OUTC)
DAC3_SDIN: U15.12 (SDIN), U84.14 (OUTB)
DAC3_SDO: U15.11 (SDO), U84.10 (INF)
DAC3_SYNC_N: U15.14 (*SYNC), U84.12 (OUTD)
DAC3_VOUT: U15.2 (VOUT), U61.3 (IN+)
DAC4_INV: C50.1, U17.1 (INV), U62.2 (IN-)
DAC4_LDAC_N: U17.8 (*LDAC), U85.15 (OUTA)
DAC4_RFB: C50.2, R19.1, U17.20 (RFB), U62.6 (OUT)
DAC4_SCLK: U17.13 (SCLK), U85.13 (OUTC)
DAC4_SDIN: U17.12 (SDIN), U85.14 (OUTB)
DAC4_SDO: U17.11 (SDO), U85.10 (INF)
DAC4_SYNC_N: U17.14 (*SYNC), U85.12 (OUTD)
DAC4_VOUT: U17.2 (VOUT), U62.3 (IN+)
DAC5_INV: C51.1, U19.1 (INV), U63.2 (IN-)
DAC5_LDAC_N: U19.8 (*LDAC), U86.15 (OUTA)
DAC5_RFB: C51.2, R20.1, U19.20 (RFB), U63.6 (OUT)
DAC5_SCLK: U19.13 (SCLK), U86.13 (OUTC)
DAC5_SDIN: U19.12 (SDIN), U86.14 (OUTB)
DAC5_SDO: U19.11 (SDO), U86.10 (INF)
DAC5_SYNC_N: U19.14 (*SYNC), U86.12 (OUTD)
DAC5_VOUT: U19.2 (VOUT), U63.3 (IN+)
DAC6_INV: C52.1, U21.1 (INV), U64.2 (IN-)
DAC6_LDAC_N: U21.8 (*LDAC), U87.15 (OUTA)
DAC6_RFB: C52.2, R21.1, U21.20 (RFB), U64.6 (OUT)
DAC6_SCLK: U21.13 (SCLK), U87.13 (OUTC)
DAC6_SDIN: U21.12 (SDIN), U87.14 (OUTB)
DAC6_SDO: U21.11 (SDO), U87.10 (INF)
DAC6_SYNC_N: U21.14 (*SYNC), U87.12 (OUTD)
DAC6_VOUT: U21.2 (VOUT), U64.3 (IN+)
DAC7_INV: C53.1, U26.1 (INV), U65.2 (IN-)
DAC7_LDAC_N: U26.8 (*LDAC), U88.15 (OUTA)
DAC7_RFB: C53.2, R22.1, U26.20 (RFB), U65.6 (OUT)
DAC7_SCLK: U26.13 (SCLK), U88.13 (OUTC)
DAC7_SDIN: U26.12 (SDIN), U88.14 (OUTB)
DAC7_SDO: U26.11 (SDO), U88.10 (INF)
DAC7_SYNC_N: U26.14 (*SYNC), U88.12 (OUTD)
DAC7_VOUT: U26.2 (VOUT), U65.3 (IN+)
DAC8_INV: C54.1, U27.1 (INV), U66.2 (IN-)
DAC8_LDAC_N: U27.8 (*LDAC), U89.15 (OUTA)
DAC8_RFB: C54.2, R23.1, U27.20 (RFB), U66.6 (OUT)
DAC8_SCLK: U27.13 (SCLK), U89.13 (OUTC)
DAC8_SDIN: U27.12 (SDIN), U89.14 (OUTB)
DAC8_SDO: U27.11 (SDO), U89.10 (INF)
DAC8_SYNC_N: U27.14 (*SYNC), U89.12 (OUTD)
DAC8_VOUT: U27.2 (VOUT), U66.3 (IN+)
DAC9_INV: C55.1, U28.1 (INV), U67.2 (IN-)
DAC9_LDAC_N: U28.8 (*LDAC), U90.15 (OUTA)
DAC9_RFB: C55.2, R24.1, U28.20 (RFB), U67.6 (OUT)
DAC9_SCLK: U28.13 (SCLK), U90.13 (OUTC)
DAC9_SDIN: U28.12 (SDIN), U90.14 (OUTB)
DAC9_SDO: U28.11 (SDO), U90.10 (INF)
DAC9_SYNC_N: U28.14 (*SYNC), U90.12 (OUTD)
DAC9_VOUT: U28.2 (VOUT), U67.3 (IN+)
DAC10_INV: C56.1, U29.1 (INV), U68.2 (IN-)
DAC10_LDAC_N: U29.8 (*LDAC), U91.15 (OUTA)
DAC10_RFB: C56.2, R25.1, U29.20 (RFB), U68.6 (OUT)
DAC10_SCLK: U29.13 (SCLK), U91.13 (OUTC)
DAC10_SDIN: U29.12 (SDIN), U91.14 (OUTB)
DAC10_SDO: U29.11 (SDO), U91.10 (INF)
DAC10_SYNC_N: U29.14 (*SYNC), U91.12 (OUTD)
DAC10_VOUT: U29.2 (VOUT), U68.3 (IN+)
DAC11_INV: C57.1, U32.1 (INV), U69.2 (IN-)
DAC11_LDAC_N: U32.8 (*LDAC), U92.15 (OUTA)
DAC11_RFB: C57.2, R26.1, U32.20 (RFB), U69.6 (OUT)
DAC11_SCLK: U32.13 (SCLK), U92.13 (OUTC)
DAC11_SDIN: U32.12 (SDIN), U92.14 (OUTB)
DAC11_SDO: U32.11 (SDO), U92.10 (INF)
DAC11_SYNC_N: U32.14 (*SYNC), U92.12 (OUTD)
DAC11_VOUT: U32.2 (VOUT), U69.3 (IN+)
DAC12_INV: C58.1, U33.1 (INV), U70.2 (IN-)
DAC12_LDAC_N: U33.8 (*LDAC), U93.15 (OUTA)
DAC12_RFB: C58.2, R27.1, U33.20 (RFB), U70.6 (OUT)
DAC12_SCLK: U33.13 (SCLK), U93.13 (OUTC)
DAC12_SDIN: U33.12 (SDIN), U93.14 (OUTB)
DAC12_SDO: U33.11 (SDO), U93.10 (INF)
DAC12_SYNC_N: U33.14 (*SYNC), U93.12 (OUTD)
DAC12_VOUT: U33.2 (VOUT), U70.3 (IN+)
DAC13_INV: C59.1, U38.1 (INV), U71.2 (IN-)
DAC13_LDAC_N: U38.8 (*LDAC), U94.15 (OUTA)
DAC13_RFB: C59.2, R28.1, U38.20 (RFB), U71.6 (OUT)
DAC13_SCLK: U38.13 (SCLK), U94.13 (OUTC)
DAC13_SDIN: U38.12 (SDIN), U94.14 (OUTB)
DAC13_SDO: U38.11 (SDO), U94.10 (INF)
DAC13_SYNC_N: U38.14 (*SYNC), U94.12 (OUTD)
DAC13_VOUT: U38.2 (VOUT), U71.3 (IN+)
DAC14_INV: C60.1, U39.1 (INV), U72.2 (IN-)
DAC14_LDAC_N: U39.8 (*LDAC), U95.15 (OUTA)
DAC14_RFB: C60.2, R29.1, U39.20 (RFB), U72.6 (OUT)
DAC14_SCLK: U39.13 (SCLK), U95.13 (OUTC)
DAC14_SDIN: U39.12 (SDIN), U95.14 (OUTB)
DAC14_SDO: U39.11 (SDO), U95.10 (INF)
DAC14_SYNC_N: U39.14 (*SYNC), U95.12 (OUTD)
DAC14_VOUT: U39.2 (VOUT), U72.3 (IN+)
DAC15_INV: C61.1, U40.1 (INV), U73.2 (IN-)
DAC15_LDAC_N: U40.8 (*LDAC), U96.15 (OUTA)
DAC15_RFB: C61.2, R30.1, U40.20 (RFB), U73.6 (OUT)
DAC15_SCLK: U40.13 (SCLK), U96.13 (OUTC)
DAC15_SDIN: U40.12 (SDIN), U96.14 (OUTB)
DAC15_SDO: U40.11 (SDO), U96.10 (INF)
DAC15_SYNC_N: U40.14 (*SYNC), U96.12 (OUTD)
DAC15_VOUT: U40.2 (VOUT), U73.3 (IN+)
DAC16_INV: C62.1, U41.1 (INV), U74.2 (IN-)
DAC16_LDAC_N: U41.8 (*LDAC), U97.15 (OUTA)
DAC16_RFB: C62.2, R31.1, U41.20 (RFB), U74.6 (OUT)
DAC16_SCLK: U41.13 (SCLK), U97.13 (OUTC)
DAC16_SDIN: U41.12 (SDIN), U97.14 (OUTB)
DAC16_SDO: U41.11 (SDO), U97.10 (INF)
DAC16_SYNC_N: U41.14 (*SYNC), U97.12 (OUTD)
DAC16_VOUT: U41.2 (VOUT), U74.3 (IN+)
DAC17_INV: C63.1, U44.1 (INV), U75.2 (IN-)
DAC17_LDAC_N: U44.8 (*LDAC), U98.15 (OUTA)
DAC17_RFB: C63.2, R32.1, U44.20 (RFB), U75.6 (OUT)
DAC17_SCLK: U44.13 (SCLK), U98.13 (OUTC)
DAC17_SDIN: U44.12 (SDIN), U98.14 (OUTB)
DAC17_SDO: U44.11 (SDO), U98.10 (INF)
DAC17_SYNC_N: U44.14 (*SYNC), U98.12 (OUTD)
DAC17_VOUT: U44.2 (VOUT), U75.3 (IN+)
DAC18_INV: C64.1, U45.1 (INV), U76.2 (IN-)
DAC18_LDAC_N: U45.8 (*LDAC), U99.15 (OUTA)
DAC18_RFB: C64.2, R33.1, U45.20 (RFB), U76.6 (OUT)
DAC18_SCLK: U45.13 (SCLK), U99.13 (OUTC)
DAC18_SDIN: U45.12 (SDIN), U99.14 (OUTB)
DAC18_SDO: U45.11 (SDO), U99.10 (INF)
DAC18_SYNC_N: U45.14 (*SYNC), U99.12 (OUTD)
DAC18_VOUT: U45.2 (VOUT), U76.3 (IN+)
DAC19_INV: C65.1, U50.1 (INV), U77.2 (IN-)
DAC19_LDAC_N: U50.8 (*LDAC), U100.15 (OUTA)
DAC19_RFB: C65.2, R34.1, U50.20 (RFB), U77.6 (OUT)
DAC19_SCLK: U50.13 (SCLK), U100.13 (OUTC)
DAC19_SDIN: U50.12 (SDIN), U100.14 (OUTB)
DAC19_SDO: U50.11 (SDO), U100.10 (INF)
DAC19_SYNC_N: U50.14 (*SYNC), U100.12 (OUTD)
DAC19_VOUT: U50.2 (VOUT), U77.3 (IN+)
DAC20_INV: C66.1, U51.1 (INV), U78.2 (IN-)
DAC20_LDAC_N: U51.8 (*LDAC), U101.15 (OUTA)
DAC20_RFB: C66.2, R35.1, U51.20 (RFB), U78.6 (OUT)
DAC20_SCLK: U51.13 (SCLK), U101.13 (OUTC)
DAC20_SDIN: U51.12 (SDIN), U101.14 (OUTB)
DAC20_SDO: U51.11 (SDO), U101.10 (INF)
DAC20_SYNC_N: U51.14 (*SYNC), U101.12 (OUTD)
DAC20_VOUT: U51.2 (VOUT), U78.3 (IN+)
DAC21_INV: C67.1, U52.1 (INV), U79.2 (IN-)
DAC21_LDAC_N: U52.8 (*LDAC), U102.15 (OUTA)
DAC21_RFB: C67.2, R36.1, U52.20 (RFB), U79.6 (OUT)
DAC21_SCLK: U52.13 (SCLK), U102.13 (OUTC)
DAC21_SDIN: U52.12 (SDIN), U102.14 (OUTB)
DAC21_SDO: U52.11 (SDO), U102.10 (INF)
DAC21_SYNC_N: U52.14 (*SYNC), U102.12 (OUTD)
DAC21_VOUT: U52.2 (VOUT), U79.3 (IN+)
DAC22_INV: C68.1, U53.1 (INV), U80.2 (IN-)
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

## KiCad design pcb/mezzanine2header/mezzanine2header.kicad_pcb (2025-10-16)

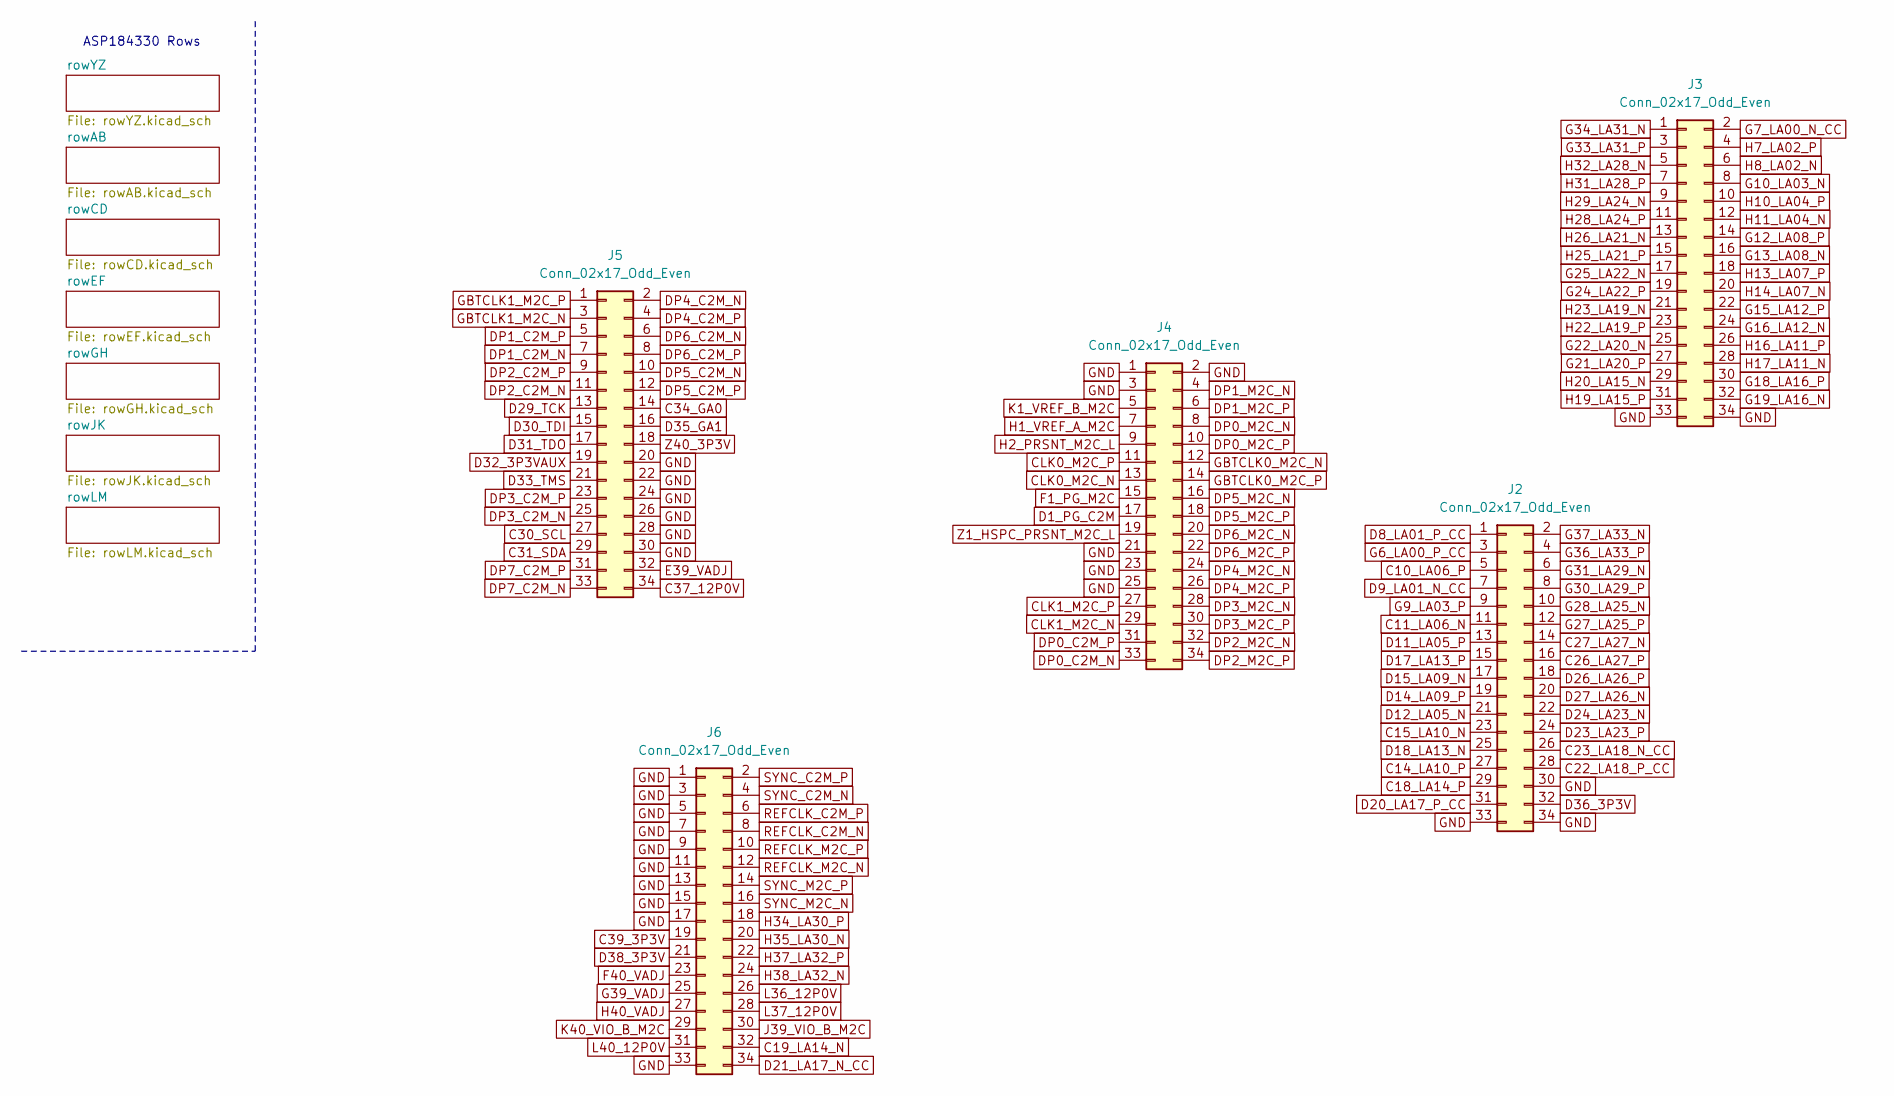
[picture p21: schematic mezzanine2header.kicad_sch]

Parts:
J2, J3, J4, J5, J6: Conn_02x17_Odd_Even; PinHeader_2x17_P2.00mm_Vertical

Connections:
C10_LA06_P: J2.5; also elsewhere on the board
C11_LA06_N: J2.11; also elsewhere on the board
C14_LA10_P: J2.27; also elsewhere on the board
C15_LA10_N: J2.23; also elsewhere on the board
C18_LA14_P: J2.29; also elsewhere on the board
C19_LA14_N: J6.32; also elsewhere on the board
C22_LA18_P_CC: J2.28; also elsewhere on the board
C23_LA18_N_CC: J2.26; also elsewhere on the board
C26_LA27_P: J2.16; also elsewhere on the board
C27_LA27_N: J2.14; also elsewhere on the board
C30_SCL: J5.27; also elsewhere on the board
C31_SDA: J5.29; also elsewhere on the board
C34_GA0: J5.14; also elsewhere on the board
C37_12P0V: J5.34; also elsewhere on the board
C39_3P3V: J6.19; also elsewhere on the board
CLK0_M2C_N: J4.13; also elsewhere on the board
CLK0_M2C_P: J4.11; also elsewhere on the board
CLK1_M2C_N: J4.29; also elsewhere on the board
CLK1_M2C_P: J4.27; also elsewhere on the board
D1_PG_C2M: J4.17; also elsewhere on the board
D8_LA01_P_CC: J2.1; also elsewhere on the board
D9_LA01_N_CC: J2.7; also elsewhere on the board
D11_LA05_P: J2.13; also elsewhere on the board
D12_LA05_N: J2.21; also elsewhere on the board
D14_LA09_P: J2.19; also elsewhere on the board
D15_LA09_N: J2.17; also elsewhere on the board
D17_LA13_P: J2.15; also elsewhere on the board
D18_LA13_N: J2.25; also elsewhere on the board
D20_LA17_P_CC: J2.31; also elsewhere on the board
D21_LA17_N_CC: J6.34; also elsewhere on the board
D23_LA23_P: J2.24; also elsewhere on the board
D24_LA23_N: J2.22; also elsewhere on the board
D26_LA26_P: J2.18; also elsewhere on the board
D27_LA26_N: J2.20; also elsewhere on the board
D29_TCK: J5.13; also elsewhere on the board
D30_TDI: J5.15; also elsewhere on the board
D31_TDO: J5.17; also elsewhere on the board
D32_3P3VAUX: J5.19; also elsewhere on the board
D33_TMS: J5.21; also elsewhere on the board
D35_GA1: J5.16; also elsewhere on the board
D36_3P3V: J2.32; also elsewhere on the board
D38_3P3V: J6.21; also elsewhere on the board
DP0_C2M_N: J4.33; also elsewhere on the board
DP0_C2M_P: J4.31; also elsewhere on the board
DP0_M2C_N: J4.8; also elsewhere on the board
DP0_M2C_P: J4.10; also elsewhere on the board
DP1_C2M_N: J5.7; also elsewhere on the board
DP1_C2M_P: J5.5; also elsewhere on the board
DP1_M2C_N: J4.4; also elsewhere on the board
DP1_M2C_P: J4.6; also elsewhere on the board
DP2_C2M_N: J5.11; also elsewhere on the board
DP2_C2M_P: J5.9; also elsewhere on the board
DP2_M2C_N: J4.32; also elsewhere on the board
DP2_M2C_P: J4.34; also elsewhere on the board
DP3_C2M_N: J5.25; also elsewhere on the board
DP3_C2M_P: J5.23; also elsewhere on the board
DP3_M2C_N: J4.28; also elsewhere on the board
DP3_M2C_P: J4.30; also elsewhere on the board
DP4_C2M_N: J5.2; also elsewhere on the board
DP4_C2M_P: J5.4; also elsewhere on the board
DP4_M2C_N: J4.24; also elsewhere on the board
DP4_M2C_P: J4.26; also elsewhere on the board
DP5_C2M_N: J5.10; also elsewhere on the board
DP5_C2M_P: J5.12; also elsewhere on the board
DP5_M2C_N: J4.16; also elsewhere on the board
DP5_M2C_P: J4.18; also elsewhere on the board
DP6_C2M_N: J5.6; also elsewhere on the board
DP6_C2M_P: J5.8; also elsewhere on the board
DP6_M2C_N: J4.20; also elsewhere on the board
DP6_M2C_P: J4.22; also elsewhere on the board
DP7_C2M_N: J5.33; also elsewhere on the board
DP7_C2M_P: J5.31; also elsewhere on the board
E39_VADJ: J5.32; also elsewhere on the board
F1_PG_M2C: J4.15; also elsewhere on the board
F40_VADJ: J6.23; also elsewhere on the board
G6_LA00_P_CC: J2.3; also elsewhere on the board
G7_LA00_N_CC: J3.2; also elsewhere on the board
G9_LA03_P: J2.9; also elsewhere on the board
G10_LA03_N: J3.8; also elsewhere on the board
G12_LA08_P: J3.14; also elsewhere on the board
G13_LA08_N: J3.16; also elsewhere on the board
G15_LA12_P: J3.22; also elsewhere on the board
G16_LA12_N: J3.24; also elsewhere on the board
G18_LA16_P: J3.30; also elsewhere on the board
G19_LA16_N: J3.32; also elsewhere on the board
G21_LA20_P: J3.27; also elsewhere on the board
G22_LA20_N: J3.25; also elsewhere on the board
G24_LA22_P: J3.19; also elsewhere on the board
G25_LA22_N: J3.17; also elsewhere on the board
G27_LA25_P: J2.12; also elsewhere on the board
G28_LA25_N: J2.10; also elsewhere on the board
G30_LA29_P: J2.8; also elsewhere on the board
G31_LA29_N: J2.6; also elsewhere on the board
G33_LA31_P: J3.3; also elsewhere on the board
G34_LA31_N: J3.1; also elsewhere on the board
G36_LA33_P: J2.4; also elsewhere on the board
G37_LA33_N: J2.2; also elsewhere on the board
G39_VADJ: J6.25; also elsewhere on the board
GBTCLK0_M2C_N: J4.12; also elsewhere on the board
GBTCLK0_M2C_P: J4.14; also elsewhere on the board
GBTCLK1_M2C_N: J5.3; also elsewhere on the board
GBTCLK1_M2C_P: J5.1; also elsewhere on the board
GND: J2.30, J2.33, J2.34, J3.33, J3.34, J4.1, J4.2, J4.3, J4.21, J4.23, J4.25, J5.20, J5.22, J5.24, J5.26, J5.28, J5.30, J6.1, J6.3, J6.5, J6.7, J6.9, J6.11, J6.13, J6.15, J6.17, J6.33; also elsewhere on the board
H1_VREF_A_M2C: J4.7; also elsewhere on the board
H2_PRSNT_M2C_L: J4.9; also elsewhere on the board
H7_LA02_P: J3.4; also elsewhere on the board
H8_LA02_N: J3.6; also elsewhere on the board
H10_LA04_P: J3.10; also elsewhere on the board
H11_LA04_N: J3.12; also elsewhere on the board
H13_LA07_P: J3.18; also elsewhere on the board
H14_LA07_N: J3.20; also elsewhere on the board
H16_LA11_P: J3.26; also elsewhere on the board
H17_LA11_N: J3.28; also elsewhere on the board
H19_LA15_P: J3.31; also elsewhere on the board
H20_LA15_N: J3.29; also elsewhere on the board
H22_LA19_P: J3.23; also elsewhere on the board
H23_LA19_N: J3.21; also elsewhere on the board
H25_LA21_P: J3.15; also elsewhere on the board
H26_LA21_N: J3.13; also elsewhere on the board
H28_LA24_P: J3.11; also elsewhere on the board
H29_LA24_N: J3.9; also elsewhere on the board
H31_LA28_P: J3.7; also elsewhere on the board
H32_LA28_N: J3.5; also elsewhere on the board
H34_LA30_P: J6.18; also elsewhere on the board
H35_LA30_N: J6.20; also elsewhere on the board
H37_LA32_P: J6.22; also elsewhere on the board
H38_LA32_N: J6.24; also elsewhere on the board
H40_VADJ: J6.27; also elsewhere on the board
J39_VIO_B_M2C: J6.30; also elsewhere on the board
K1_VREF_B_M2C: J4.5; also elsewhere on the board
K40_VIO_B_M2C: J6.29; also elsewhere on the board
L36_12P0V: J6.26; also elsewhere on the board
L37_12P0V: J6.28; also elsewhere on the board
L40_12P0V: J6.31; also elsewhere on the board
REFCLK_C2M_N: J6.8; also elsewhere on the board
REFCLK_C2M_P: J6.6; also elsewhere on the board
REFCLK_M2C_N: J6.12; also elsewhere on the board
REFCLK_M2C_P: J6.10; also elsewhere on the board
SYNC_C2M_N: J6.4; also elsewhere on the board
SYNC_C2M_P: J6.2; also elsewhere on the board
SYNC_M2C_N: J6.16; also elsewhere on the board
SYNC_M2C_P: J6.14; also elsewhere on the board
Z1_HSPC_PRSNT_M2C_L: J4.19; also elsewhere on the board
Z40_3P3V: J5.18; also elsewhere on the board

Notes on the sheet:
ASP184330 Rows

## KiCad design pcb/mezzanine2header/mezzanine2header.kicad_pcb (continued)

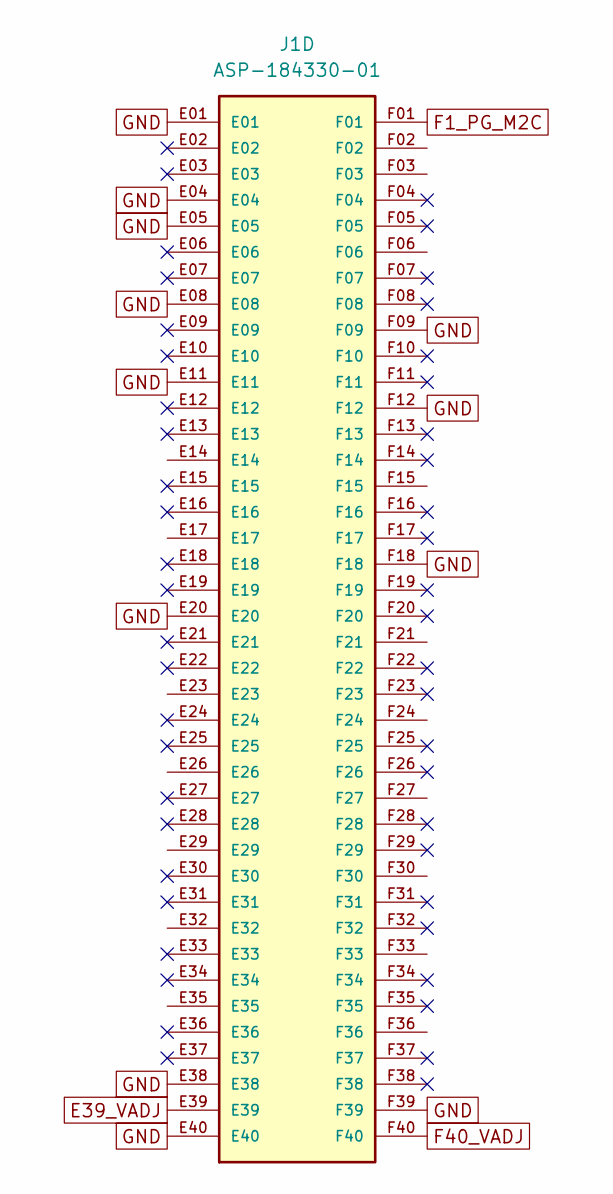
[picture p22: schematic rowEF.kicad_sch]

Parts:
J1: ASP-184330-01; SAMTEC_ASP-184330-01; PARTREV C

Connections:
E39_VADJ: J1.E39; also elsewhere on the board
F1_PG_M2C: J1.F01; also elsewhere on the board
F40_VADJ: J1.F40; also elsewhere on the board
GND: J1.E01, J1.E04, J1.E05, J1.E08, J1.E11, J1.E20, J1.E38, J1.E40, J1.F09, J1.F12, J1.F18, J1.F39; also elsewhere on the board

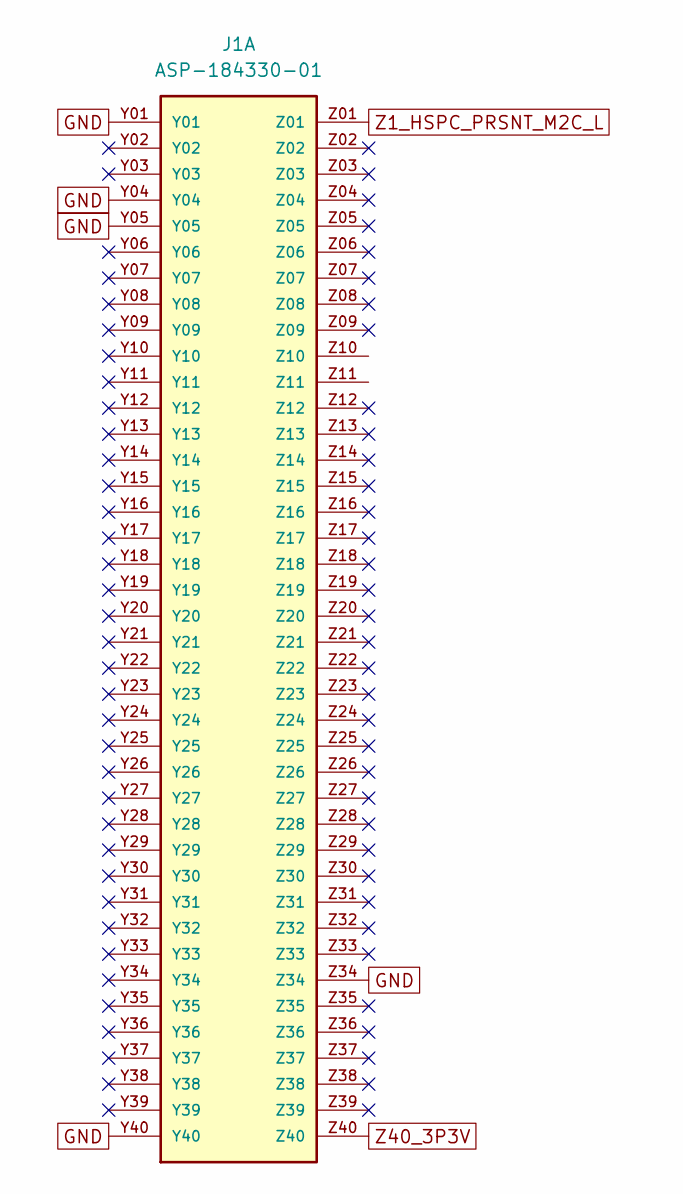
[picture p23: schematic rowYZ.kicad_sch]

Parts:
J1: ASP-184330-01; SAMTEC_ASP-184330-01; PARTREV C

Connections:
GND: J1.Y01, J1.Y04, J1.Y05, J1.Y40, J1.Z34; also elsewhere on the board
Z1_HSPC_PRSNT_M2C_L: J1.Z01; also elsewhere on the board
Z40_3P3V: J1.Z40; also elsewhere on the board

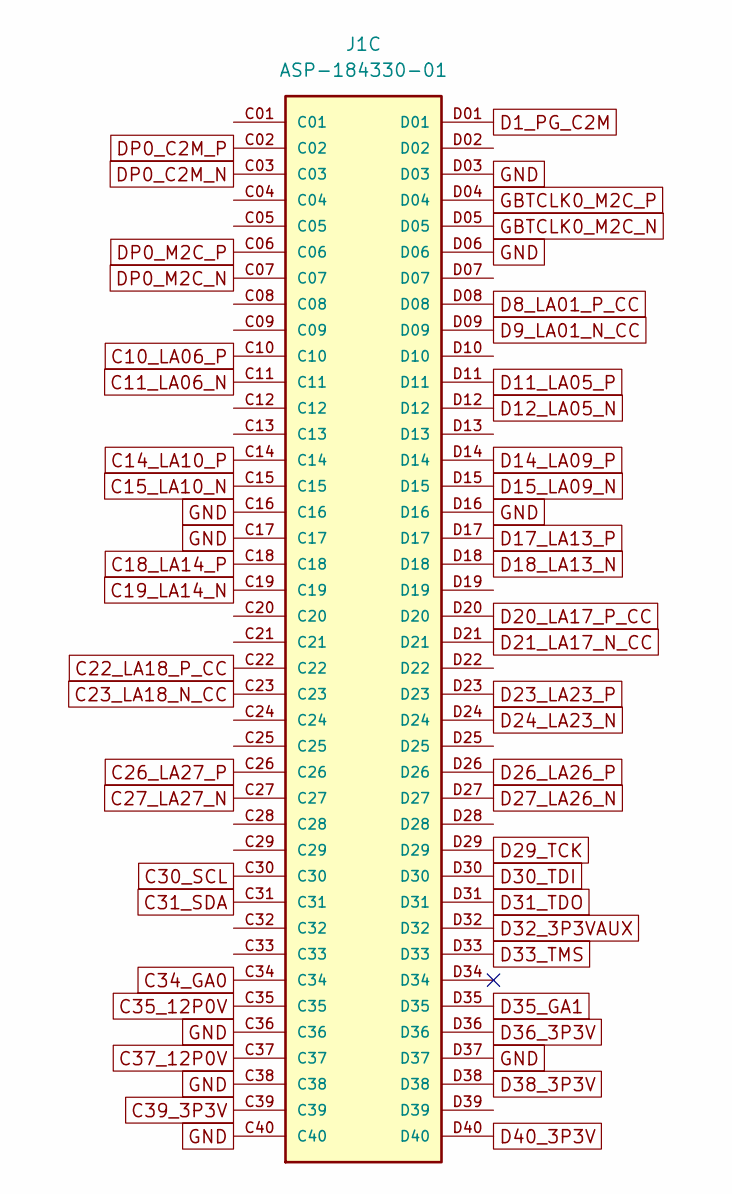
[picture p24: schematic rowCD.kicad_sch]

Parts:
J1: ASP-184330-01; SAMTEC_ASP-184330-01; PARTREV C

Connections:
C10_LA06_P: J1.C10; also elsewhere on the board
C11_LA06_N: J1.C11; also elsewhere on the board
C14_LA10_P: J1.C14; also elsewhere on the board
C15_LA10_N: J1.C15; also elsewhere on the board
C18_LA14_P: J1.C18; also elsewhere on the board
C19_LA14_N: J1.C19; also elsewhere on the board
C22_LA18_P_CC: J1.C22; also elsewhere on the board
C23_LA18_N_CC: J1.C23; also elsewhere on the board
C26_LA27_P: J1.C26; also elsewhere on the board
C27_LA27_N: J1.C27; also elsewhere on the board
C30_SCL: J1.C30; also elsewhere on the board
C31_SDA: J1.C31; also elsewhere on the board
C34_GA0: J1.C34; also elsewhere on the board
C35_12P0V: J1.C35
C37_12P0V: J1.C37; also elsewhere on the board
C39_3P3V: J1.C39; also elsewhere on the board
D1_PG_C2M: J1.D01; also elsewhere on the board
D8_LA01_P_CC: J1.D08; also elsewhere on the board
D9_LA01_N_CC: J1.D09; also elsewhere on the board
D11_LA05_P: J1.D11; also elsewhere on the board
D12_LA05_N: J1.D12; also elsewhere on the board
D14_LA09_P: J1.D14; also elsewhere on the board
D15_LA09_N: J1.D15; also elsewhere on the board
D17_LA13_P: J1.D17; also elsewhere on the board
D18_LA13_N: J1.D18; also elsewhere on the board
D20_LA17_P_CC: J1.D20; also elsewhere on the board
D21_LA17_N_CC: J1.D21; also elsewhere on the board
D23_LA23_P: J1.D23; also elsewhere on the board
D24_LA23_N: J1.D24; also elsewhere on the board
D26_LA26_P: J1.D26; also elsewhere on the board
D27_LA26_N: J1.D27; also elsewhere on the board
D29_TCK: J1.D29; also elsewhere on the board
D30_TDI: J1.D30; also elsewhere on the board
D31_TDO: J1.D31; also elsewhere on the board
D32_3P3VAUX: J1.D32; also elsewhere on the board
D33_TMS: J1.D33; also elsewhere on the board
D35_GA1: J1.D35; also elsewhere on the board
D36_3P3V: J1.D36; also elsewhere on the board
D38_3P3V: J1.D38; also elsewhere on the board
D40_3P3V: J1.D40
DP0_C2M_N: J1.C03; also elsewhere on the board
DP0_C2M_P: J1.C02; also elsewhere on the board
DP0_M2C_N: J1.C07; also elsewhere on the board
DP0_M2C_P: J1.C06; also elsewhere on the board
GBTCLK0_M2C_N: J1.D05; also elsewhere on the board
GBTCLK0_M2C_P: J1.D04; also elsewhere on the board
GND: J1.C16, J1.C17, J1.C36, J1.C38, J1.C40, J1.D03, J1.D06, J1.D16, J1.D37; also elsewhere on the board

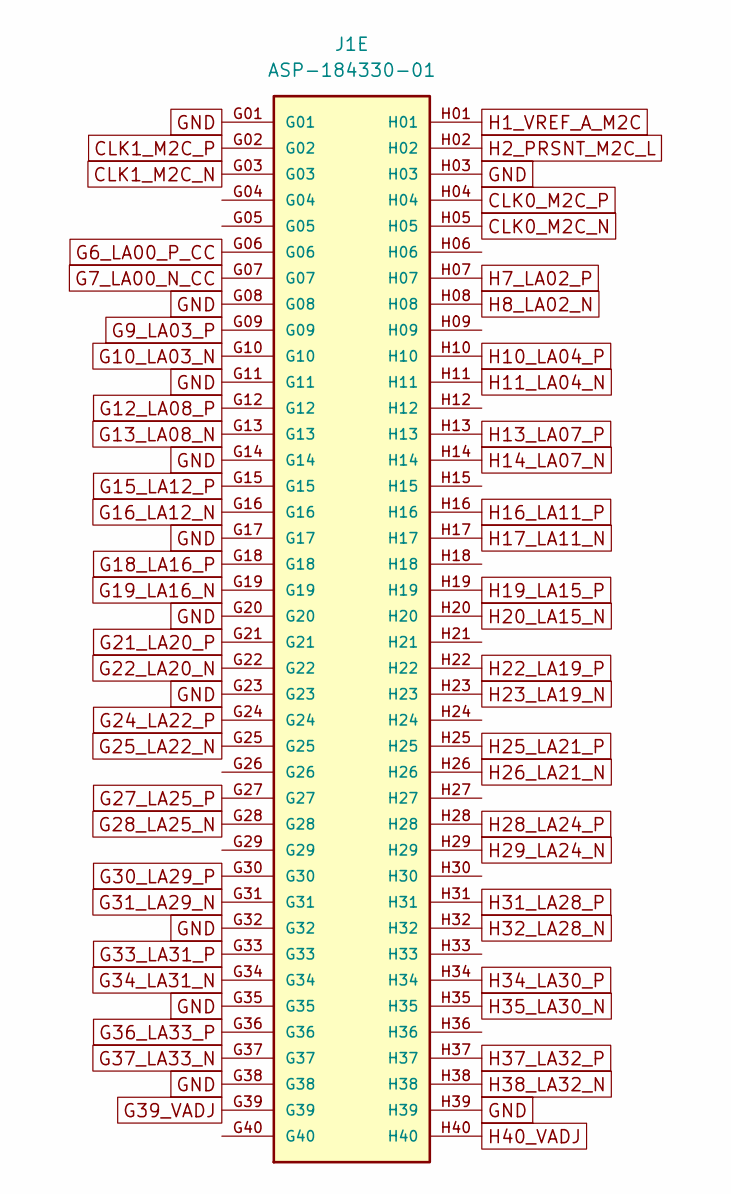
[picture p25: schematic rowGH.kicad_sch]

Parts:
J1: ASP-184330-01; SAMTEC_ASP-184330-01; PARTREV C

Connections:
CLK0_M2C_N: J1.H05; also elsewhere on the board
CLK0_M2C_P: J1.H04; also elsewhere on the board
CLK1_M2C_N: J1.G03; also elsewhere on the board
CLK1_M2C_P: J1.G02; also elsewhere on the board
G6_LA00_P_CC: J1.G06; also elsewhere on the board
G7_LA00_N_CC: J1.G07; also elsewhere on the board
G9_LA03_P: J1.G09; also elsewhere on the board
G10_LA03_N: J1.G10; also elsewhere on the board
G12_LA08_P: J1.G12; also elsewhere on the board
G13_LA08_N: J1.G13; also elsewhere on the board
G15_LA12_P: J1.G15; also elsewhere on the board
G16_LA12_N: J1.G16; also elsewhere on the board
G18_LA16_P: J1.G18; also elsewhere on the board
G19_LA16_N: J1.G19; also elsewhere on the board
G21_LA20_P: J1.G21; also elsewhere on the board
G22_LA20_N: J1.G22; also elsewhere on the board
G24_LA22_P: J1.G24; also elsewhere on the board
G25_LA22_N: J1.G25; also elsewhere on the board
G27_LA25_P: J1.G27; also elsewhere on the board
G28_LA25_N: J1.G28; also elsewhere on the board
G30_LA29_P: J1.G30; also elsewhere on the board
G31_LA29_N: J1.G31; also elsewhere on the board
G33_LA31_P: J1.G33; also elsewhere on the board
G34_LA31_N: J1.G34; also elsewhere on the board
G36_LA33_P: J1.G36; also elsewhere on the board
G37_LA33_N: J1.G37; also elsewhere on the board
G39_VADJ: J1.G39; also elsewhere on the board
GND: J1.G01, J1.G08, J1.G11, J1.G14, J1.G17, J1.G20, J1.G23, J1.G32, J1.G35, J1.G38, J1.H03, J1.H39; also elsewhere on the board
H1_VREF_A_M2C: J1.H01; also elsewhere on the board
H2_PRSNT_M2C_L: J1.H02; also elsewhere on the board
H7_LA02_P: J1.H07; also elsewhere on the board
H8_LA02_N: J1.H08; also elsewhere on the board
H10_LA04_P: J1.H10; also elsewhere on the board
H11_LA04_N: J1.H11; also elsewhere on the board
H13_LA07_P: J1.H13; also elsewhere on the board
H14_LA07_N: J1.H14; also elsewhere on the board
H16_LA11_P: J1.H16; also elsewhere on the board
H17_LA11_N: J1.H17; also elsewhere on the board
H19_LA15_P: J1.H19; also elsewhere on the board
H20_LA15_N: J1.H20; also elsewhere on the board
H22_LA19_P: J1.H22; also elsewhere on the board
H23_LA19_N: J1.H23; also elsewhere on the board
H25_LA21_P: J1.H25; also elsewhere on the board
H26_LA21_N: J1.H26; also elsewhere on the board
H28_LA24_P: J1.H28; also elsewhere on the board
H29_LA24_N: J1.H29; also elsewhere on the board
H31_LA28_P: J1.H31; also elsewhere on the board
H32_LA28_N: J1.H32; also elsewhere on the board
H34_LA30_P: J1.H34; also elsewhere on the board
H35_LA30_N: J1.H35; also elsewhere on the board
H37_LA32_P: J1.H37; also elsewhere on the board
H38_LA32_N: J1.H38; also elsewhere on the board
H40_VADJ: J1.H40; also elsewhere on the board

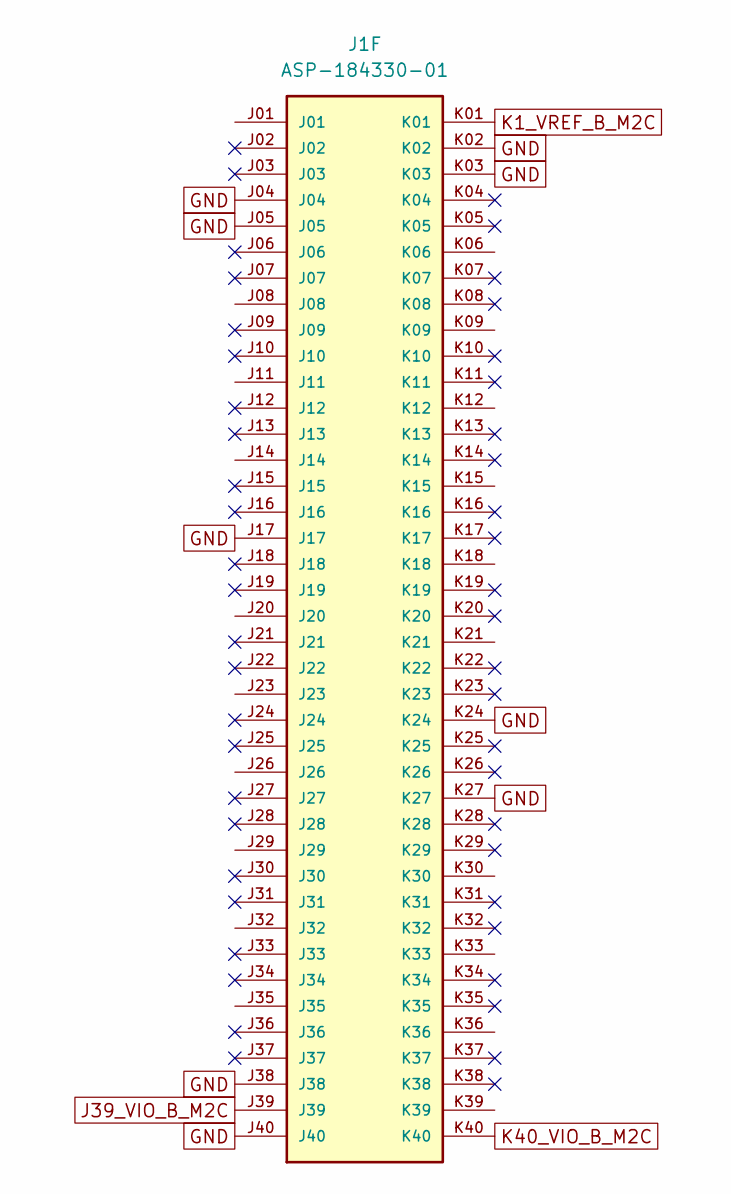
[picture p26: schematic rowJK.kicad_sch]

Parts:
J1: ASP-184330-01; SAMTEC_ASP-184330-01; PARTREV C

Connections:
GND: J1.J04, J1.J05, J1.J17, J1.J38, J1.J40, J1.K02, J1.K03, J1.K24, J1.K27; also elsewhere on the board
J39_VIO_B_M2C: J1.J39; also elsewhere on the board
K1_VREF_B_M2C: J1.K01; also elsewhere on the board
K40_VIO_B_M2C: J1.K40; also elsewhere on the board

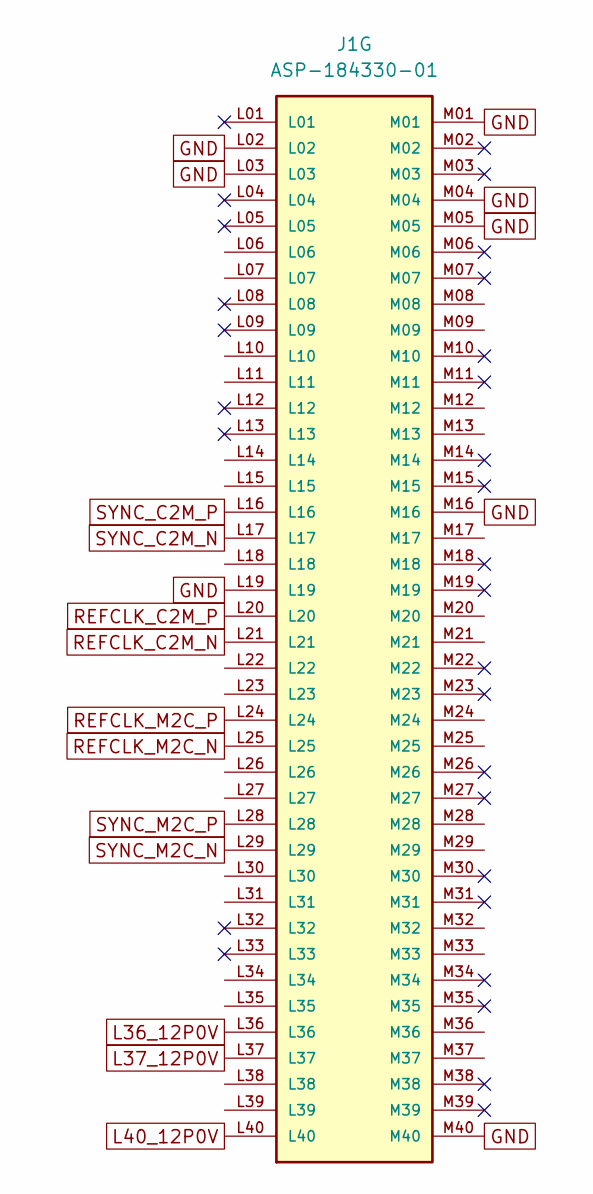
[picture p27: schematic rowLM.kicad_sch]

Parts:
J1: ASP-184330-01; SAMTEC_ASP-184330-01; PARTREV C

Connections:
GND: J1.L02, J1.L03, J1.L19, J1.M01, J1.M04, J1.M05, J1.M16, J1.M40; also elsewhere on the board
L36_12P0V: J1.L36; also elsewhere on the board
L37_12P0V: J1.L37; also elsewhere on the board
L40_12P0V: J1.L40; also elsewhere on the board
REFCLK_C2M_N: J1.L21; also elsewhere on the board
REFCLK_C2M_P: J1.L20; also elsewhere on the board
REFCLK_M2C_N: J1.L25; also elsewhere on the board
REFCLK_M2C_P: J1.L24; also elsewhere on the board
SYNC_C2M_N: J1.L17; also elsewhere on the board
SYNC_C2M_P: J1.L16; also elsewhere on the board
SYNC_M2C_N: J1.L29; also elsewhere on the board
SYNC_M2C_P: J1.L28; also elsewhere on the board

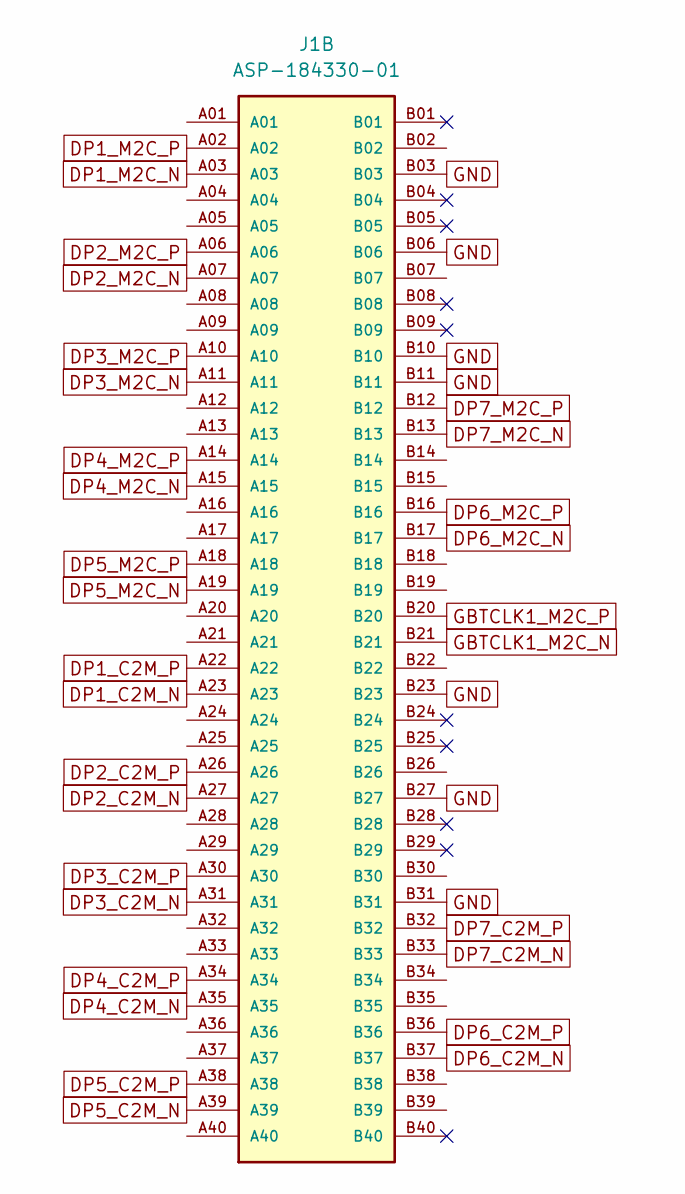
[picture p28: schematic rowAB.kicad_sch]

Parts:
J1: ASP-184330-01; SAMTEC_ASP-184330-01; PARTREV C

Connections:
DP1_C2M_N: J1.A23; also elsewhere on the board
DP1_C2M_P: J1.A22; also elsewhere on the board
DP1_M2C_N: J1.A03; also elsewhere on the board
DP1_M2C_P: J1.A02; also elsewhere on the board
DP2_C2M_N: J1.A27; also elsewhere on the board
DP2_C2M_P: J1.A26; also elsewhere on the board
DP2_M2C_N: J1.A07; also elsewhere on the board
DP2_M2C_P: J1.A06; also elsewhere on the board
DP3_C2M_N: J1.A31; also elsewhere on the board
DP3_C2M_P: J1.A30; also elsewhere on the board
DP3_M2C_N: J1.A11; also elsewhere on the board
DP3_M2C_P: J1.A10; also elsewhere on the board
DP4_C2M_N: J1.A35; also elsewhere on the board
DP4_C2M_P: J1.A34; also elsewhere on the board
DP4_M2C_N: J1.A15; also elsewhere on the board
DP4_M2C_P: J1.A14; also elsewhere on the board
DP5_C2M_N: J1.A39; also elsewhere on the board
DP5_C2M_P: J1.A38; also elsewhere on the board
DP5_M2C_N: J1.A19; also elsewhere on the board
DP5_M2C_P: J1.A18; also elsewhere on the board
DP6_C2M_N: J1.B37; also elsewhere on the board
DP6_C2M_P: J1.B36; also elsewhere on the board
DP6_M2C_N: J1.B17; also elsewhere on the board
DP6_M2C_P: J1.B16; also elsewhere on the board
DP7_C2M_N: J1.B33; also elsewhere on the board
DP7_C2M_P: J1.B32; also elsewhere on the board
DP7_M2C_N: J1.B13
DP7_M2C_P: J1.B12
GBTCLK1_M2C_N: J1.B21; also elsewhere on the board
GBTCLK1_M2C_P: J1.B20; also elsewhere on the board
GND: J1.B03, J1.B06, J1.B10, J1.B11, J1.B23, J1.B27, J1.B31; also elsewhere on the board

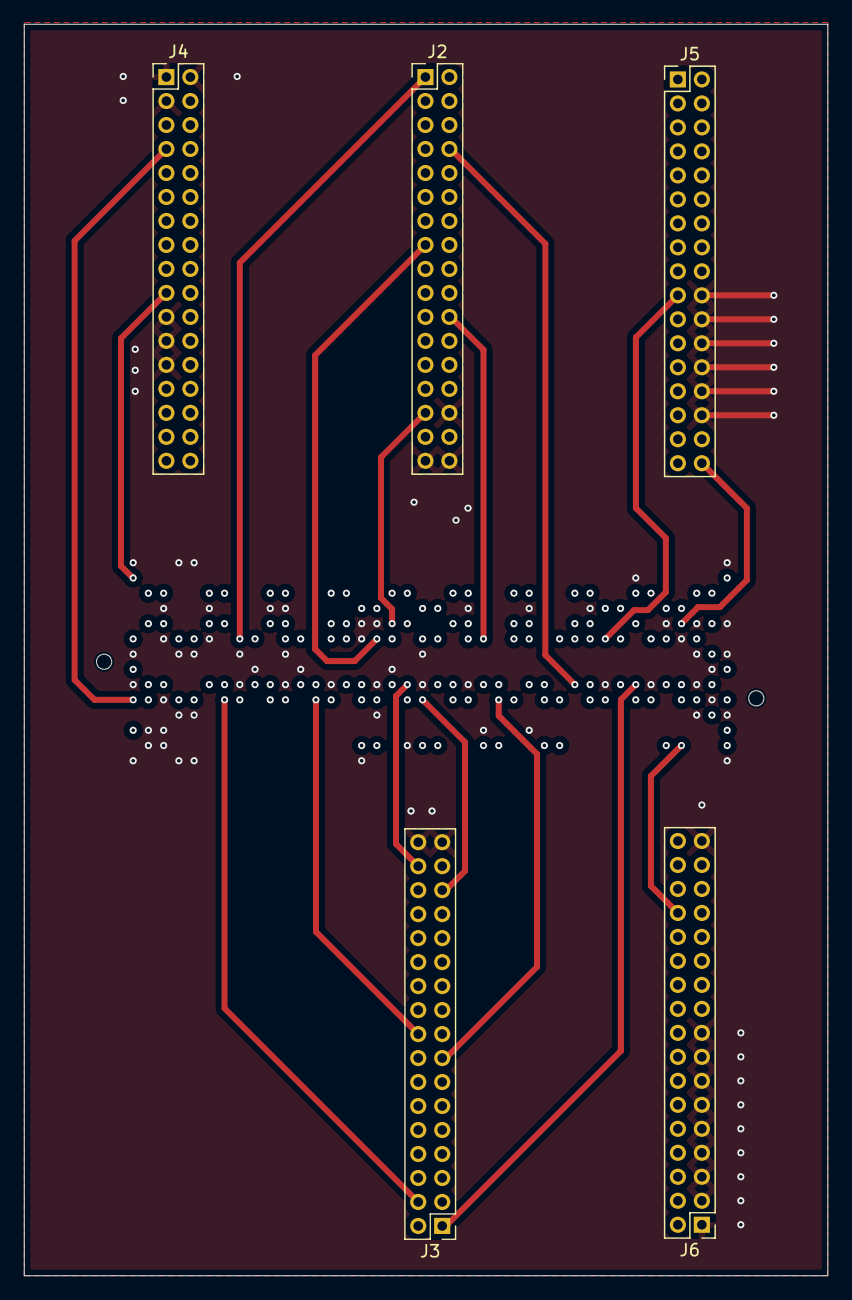
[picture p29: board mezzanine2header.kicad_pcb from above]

Board: 16 copper layers, 67.0 x 104.3 mm, 6 parts (1 on the bottom side), 144 nets.

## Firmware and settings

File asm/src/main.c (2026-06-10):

#include "common.h"
#include "asm.h"
#include "disasm.h"
#include "dc.h"
#include "rf.h"
#include "li.h"
#include "ex.h"
#include "launch.h"
#include <stdio.h>
#include <stdlib.h>
#include <unistd.h>
#include <inttypes.h>

static void free_programs(dc_program_t *dc[], rf_program_t *rf[],
                          li_program_t *li[], ex_program_t *ex[],
                          launch_t *launch) {
    for (int i = 0; i < DC_CHANNELS; i++) { if (dc[i]) free(dc[i]); }
    for (int i = 0; i < RF_CHANNELS; i++) { if (rf[i]) free(rf[i]); }
    for (int i = 0; i < LI_CHANNELS; i++) { if (li[i]) free(li[i]); }
    for (int i = 0; i < EX_CHANNELS; i++) { if (ex[i]) free(ex[i]); }
    if (launch) free(launch);
}

int main(int argc, char *argv[]) {

    int   opt;
    char *file  = NULL;  /* -f: input .asm file */
    char *out   = NULL;  /* -o: output bin file */
    char *disf  = NULL;  /* -d: input bin file to disassemble */
    char *rdev  = NULL;  /* -r: channel name to inspect via UIO */
    int   sim   = 0;
    int   exe   = 0;

    while ((opt = getopt(argc, argv, "f:o:d:r:sx")) != -1) {
        switch (opt) {
            case 'f': file = optarg; break;
            case 'o': out  = optarg; break;
            case 'd': disf = optarg; break;
            case 'r': rdev = optarg; break;
            case 's': sim  = 1;      break;
            case 'x': exe  = 1;      break;
            default:
                fprintf(stderr,
                    "Usage: %s [-f file.asm] [-o out] [-s] [-x] [-r ch] [-d file.bin]\n",
                    argv[0]);
                return 1;
        }
    }

    if (file == NULL && disf == NULL && rdev == NULL) {
        fprintf(stderr,
            "Usage: %s [-f file.asm] [-o out] [-s] [-x] [-r ch] [-d file.bin]\n",
            argv[0]);
        return 1;
    }

    dc_program_t *dc_programs[DC_CHANNELS] = {NULL};
    rf_program_t *rf_programs[RF_CHANNELS] = {NULL};
    li_program_t *li_programs[LI_CHANNELS] = {NULL};
    ex_program_t *ex_programs[EX_CHANNELS] = {NULL};
    launch_t     *launch                   = NULL;

    /* -f: assemble .asm → bin */
    if (file != NULL) {
        FILE *fp = fopen(file, "r");
        if (fp == NULL) { perror(file); return 1; }
        assemble(fp, dc_programs, rf_programs, li_programs, ex_programs, &launch);
        fclose(fp);

        const char *binpath = out ? out : "out.bin";
        FILE *op = fopen(binpath, "w");
        if (op == NULL) { perror(binpath); return 1; }
        write_bin(dc_programs, rf_programs, li_programs, ex_programs, launch, op);
        fclose(op);

        printf("program t: %"PRIu64" ns\n",
               program_t(dc_programs, rf_programs, li_programs, ex_programs));
    }

    /* -s: send to simulator */
    if (sim) {
        printf("simulate\n");
        write_sim(dc_programs, rf_programs, li_programs, ex_programs, launch);
    }

    /* -x: load onto hardware via UIO */
    if (exe) {
        for (int ch = 0; ch < DC_CHANNELS; ch++)
            if (dc_programs[ch]) dc_load_insns(ch, dc_programs[ch]);
        for (int ch = 0; ch < RF_CHANNELS; ch++)
            if (rf_programs[ch]) rf_load_insns(ch, rf_programs[ch]);
        for (int ch = 0; ch < LI_CHANNELS; ch++)
            if (li_programs[ch]) li_load_insns(ch, li_programs[ch]);
        for (int ch = 0; ch < EX_CHANNELS; ch++)
            if (ex_programs[ch]) ex_load_insns(ch, ex_programs[ch]);
        if (launch) launch_load(launch);
    }

    free_programs(dc_programs, rf_programs, li_programs, ex_programs, launch);
    launch = NULL;
    for (int i = 0; i < DC_CHANNELS; i++) dc_programs[i] = NULL;
    for (int i = 0; i < RF_CHANNELS; i++) rf_programs[i] = NULL;
    for (int i = 0; i < LI_CHANNELS; i++) li_programs[i] = NULL;
    for (int i = 0; i < EX_CHANNELS; i++) ex_programs[i] = NULL;

    /* -d: disassemble bin → stdout (or -o file) */
    if (disf != NULL) {
        FILE *fp = fopen(disf, "r");
        if (fp == NULL) { perror(disf); return 1; }
        disassemble(fp, dc_programs, rf_programs, li_programs, ex_programs, &launch);
        fclose(fp);

        const char *asmpath = out ? out : "out.asm";
        FILE *aout = fopen(asmpath, "w");
        if (aout == NULL) { perror(asmpath); return 1; }
        write_asm(aout, dc_programs, rf_programs, li_programs, ex_programs, launch);
        fclose(aout);
        printf("disassembled to %s\n", asmpath);

        free_programs(dc_programs, rf_programs, li_programs, ex_programs, launch);
    }

    /* -r: inspect a live channel via UIO */
    if (rdev != NULL)
        return inspect_named_channel(rdev);

    return 0;
}

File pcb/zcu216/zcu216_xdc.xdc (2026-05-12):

#######################################################
##                                                   ##
## ZCU216 Master XDC                                 ##
## Date: 10 MAR 2020                                 ##
##                                                   ##
#######################################################
set_property PACKAGE_PIN A18        [get_ports "PL_DDR4_C1_CKE"] ;# Bank  69 VCCO - VCC1V2   - IO_L24N_T3U_N11_69
set_property IOSTANDARD  SSTL12_DCI [get_ports "PL_DDR4_C1_CKE"] ;# Bank  69 VCCO - VCC1V2   - IO_L24N_T3U_N11_69
set_property PACKAGE_PIN B18        [get_ports "PL_DDR4_C1_RESET_B"] ;# Bank  69 VCCO - VCC1V2   - IO_L24P_T3U_N10_69
set_property IOSTANDARD  LVCMOS12   [get_ports "PL_DDR4_C1_RESET_B"] ;# Bank  69 VCCO - VCC1V2   - IO_L24P_T3U_N10_69
set_property PACKAGE_PIN A19        [get_ports "PL_DDR4_C1_CAS_B"] ;# Bank  69 VCCO - VCC1V2   - IO_L23N_T3U_N9_69
set_property IOSTANDARD  SSTL12_DCI [get_ports "PL_DDR4_C1_CAS_B"] ;# Bank  69 VCCO - VCC1V2   - IO_L23N_T3U_N9_69
set_property PACKAGE_PIN A20        [get_ports "PL_DDR4_C1_CS_B"] ;# Bank  69 VCCO - VCC1V2   - IO_L23P_T3U_N8_69
set_property IOSTANDARD  SSTL12_DCI [get_ports "PL_DDR4_C1_CS_B"] ;# Bank  69 VCCO - VCC1V2   - IO_L23P_T3U_N8_69
set_property PACKAGE_PIN A17        [get_ports "PL_DDR4_C1_WE_B"] ;# Bank  69 VCCO - VCC1V2   - IO_L22N_T3U_N7_DBC_AD0N_69
set_property IOSTANDARD  SSTL12_DCI [get_ports "PL_DDR4_C1_WE_B"] ;# Bank  69 VCCO - VCC1V2   - IO_L22N_T3U_N7_DBC_AD0N_69
set_property PACKAGE_PIN B17        [get_ports "PL_DDR4_C1_ALERT_B"] ;# Bank  69 VCCO - VCC1V2   - IO_L22P_T3U_N6_DBC_AD0P_69
set_property IOSTANDARD  SSTL12_DCI [get_ports "PL_DDR4_C1_ALERT_B"] ;# Bank  69 VCCO - VCC1V2   - IO_L22P_T3U_N6_DBC_AD0P_69
set_property PACKAGE_PIN B20        [get_ports "PL_DDR4_C1_BG0"] ;# Bank  69 VCCO - VCC1V2   - IO_L21N_T3L_N5_AD8N_69
set_property IOSTANDARD  SSTL12_DCI [get_ports "PL_DDR4_C1_BG0"] ;# Bank  69 VCCO - VCC1V2   - IO_L21N_T3L_N5_AD8N_69
set_property PACKAGE_PIN B21        [get_ports "PL_DDR4_C1_BG1"] ;# Bank  69 VCCO - VCC1V2   - IO_L21P_T3L_N4_AD8P_69
set_property IOSTANDARD  SSTL12_DCI [get_ports "PL_DDR4_C1_BG1"] ;# Bank  69 VCCO - VCC1V2   - IO_L21P_T3L_N4_AD8P_69
set_property PACKAGE_PIN C18        [get_ports "PL_DDR4_C1_ACT_B"] ;# Bank  69 VCCO - VCC1V2   - IO_L20N_T3L_N3_AD1N_69
set_property IOSTANDARD  SSTL12_DCI [get_ports "PL_DDR4_C1_ACT_B"] ;# Bank  69 VCCO - VCC1V2   - IO_L20N_T3L_N3_AD1N_69
set_property PACKAGE_PIN C19        [get_ports "PL_DDR4_C1_ODT"] ;# Bank  69 VCCO - VCC1V2   - IO_L20P_T3L_N2_AD1P_69
set_property IOSTANDARD  SSTL12_DCI [get_ports "PL_DDR4_C1_ODT"] ;# Bank  69 VCCO - VCC1V2   - IO_L20P_T3L_N2_AD1P_69
set_property PACKAGE_PIN C21        [get_ports "PL_DDR4_C1_RAS_B"] ;# Bank  69 VCCO - VCC1V2   - IO_L19N_T3L_N1_DBC_AD9N_69
set_property IOSTANDARD  SSTL12_DCI [get_ports "PL_DDR4_C1_RAS_B"] ;# Bank  69 VCCO - VCC1V2   - IO_L19N_T3L_N1_DBC_AD9N_69
set_property PACKAGE_PIN D21        [get_ports "PL_DDR4_C1_A0"] ;# Bank  69 VCCO - VCC1V2   - IO_L19P_T3L_N0_DBC_AD9P_69
set_property IOSTANDARD  SSTL12_DCI [get_ports "PL_DDR4_C1_A0"] ;# Bank  69 VCCO - VCC1V2   - IO_L19P_T3L_N0_DBC_AD9P_69
set_property PACKAGE_PIN C20        [get_ports "PL_DDR4_C1_PARITY"] ;# Bank  69 VCCO - VCC1V2   - IO_T3U_N12_69
set_property IOSTANDARD  SSTL12_DCI [get_ports "PL_DDR4_C1_PARITY"] ;# Bank  69 VCCO - VCC1V2   - IO_T3U_N12_69
set_property PACKAGE_PIN E19        [get_ports "PL_DDR4_C1_A1"] ;# Bank  69 VCCO - VCC1V2   - IO_T2U_N12_69
set_property IOSTANDARD  SSTL12_DCI [get_ports "PL_DDR4_C1_A1"] ;# Bank  69 VCCO - VCC1V2   - IO_T2U_N12_69
set_property PACKAGE_PIN D18        [get_ports "PL_DDR4_C1_A2"] ;# Bank  69 VCCO - VCC1V2   - IO_L18N_T2U_N11_AD2N_69
set_property IOSTANDARD  SSTL12_DCI [get_ports "PL_DDR4_C1_A2"] ;# Bank  69 VCCO - VCC1V2   - IO_L18N_T2U_N11_AD2N_69
set_property PACKAGE_PIN D19        [get_ports "PL_DDR4_C1_A3"] ;# Bank  69 VCCO - VCC1V2   - IO_L18P_T2U_N10_AD2P_69
set_property IOSTANDARD  SSTL12_DCI [get_ports "PL_DDR4_C1_A3"] ;# Bank  69 VCCO - VCC1V2   - IO_L18P_T2U_N10_AD2P_69
set_property PACKAGE_PIN E20        [get_ports "PL_DDR4_C1_A4"] ;# Bank  69 VCCO - VCC1V2   - IO_L17N_T2U_N9_AD10N_69
set_property IOSTANDARD  SSTL12_DCI [get_ports "PL_DDR4_C1_A4"] ;# Bank  69 VCCO - VCC1V2   - IO_L17N_T2U_N9_AD10N_69
set_property PACKAGE_PIN E21        [get_ports "PL_DDR4_C1_A5"] ;# Bank  69 VCCO - VCC1V2   - IO_L17P_T2U_N8_AD10P_69
set_property IOSTANDARD  SSTL12_DCI [get_ports "PL_DDR4_C1_A5"] ;# Bank  69 VCCO - VCC1V2   - IO_L17P_T2U_N8_AD10P_69
set_property PACKAGE_PIN D17        [get_ports "PL_DDR4_C1_A6"] ;# Bank  69 VCCO - VCC1V2   - IO_L16N_T2U_N7_QBC_AD3N_69
set_property IOSTANDARD  SSTL12_DCI [get_ports "PL_DDR4_C1_A6"] ;# Bank  69 VCCO - VCC1V2   - IO_L16N_T2U_N7_QBC_AD3N_69
set_property PACKAGE_PIN E17        [get_ports "PL_DDR4_C1_A7"] ;# Bank  69 VCCO - VCC1V2   - IO_L16P_T2U_N6_QBC_AD3P_69
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

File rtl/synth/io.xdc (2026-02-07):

#J2
set_property -dict {PACKAGE_PIN G27 IOSTANDARD LVCMOS18} [get_ports o_la01_p]
set_property -dict {PACKAGE_PIN F30 IOSTANDARD LVCMOS18} [get_ports i_la00_p]
set_property -dict {PACKAGE_PIN E27 IOSTANDARD LVCMOS18} [get_ports o_la06_p]
set_property -dict {PACKAGE_PIN G28 IOSTANDARD LVCMOS18} [get_ports o_la01_n]
set_property -dict {PACKAGE_PIN B30 IOSTANDARD LVCMOS18} [get_ports o_la03_p]
set_property -dict {PACKAGE_PIN D27 IOSTANDARD LVCMOS18} [get_ports o_la06_n]
set_property -dict {PACKAGE_PIN F29 IOSTANDARD LVCMOS18} [get_ports o_la05_p]
set_property -dict {PACKAGE_PIN J27 IOSTANDARD LVCMOS18} [get_ports i_la13_p]
set_property -dict {PACKAGE_PIN F28 IOSTANDARD LVCMOS18} [get_ports o_la09_n]
set_property -dict {PACKAGE_PIN F27 IOSTANDARD LVCMOS18} [get_ports o_la09_p]
set_property -dict {PACKAGE_PIN E29 IOSTANDARD LVCMOS18} [get_ports o_la05_n]
set_property -dict {PACKAGE_PIN L29 IOSTANDARD LVCMOS18} [get_ports o_la10_n]
set_property -dict {PACKAGE_PIN J28 IOSTANDARD LVCMOS18} [get_ports i_la13_n]
set_property -dict {PACKAGE_PIN L28 IOSTANDARD LVCMOS18} [get_ports o_la10_p]
set_property -dict {PACKAGE_PIN B27 IOSTANDARD LVCMOS18} [get_ports o_la14_p]
set_property -dict {PACKAGE_PIN AP22 IOSTANDARD LVCMOS18} [get_ports o_la17_p]
set_property -dict {PACKAGE_PIN AK24 IOSTANDARD LVCMOS18} [get_ports i_la33_n]
set_property -dict {PACKAGE_PIN AJ23 IOSTANDARD LVCMOS18} [get_ports o_la33_p]
set_property -dict {PACKAGE_PIN AM25 IOSTANDARD LVCMOS18} [get_ports o_la29_n]
set_property -dict {PACKAGE_PIN AL24 IOSTANDARD LVCMOS18} [get_ports o_la29_p]
set_property -dict {PACKAGE_PIN AN25 IOSTANDARD LVCMOS18} [get_ports i_la25_n]
set_property -dict {PACKAGE_PIN AN24 IOSTANDARD LVCMOS18} [get_ports o_la25_p]
set_property -dict {PACKAGE_PIN AV25 IOSTANDARD LVCMOS18} [get_ports o_la27_n]
set_property -dict {PACKAGE_PIN AU25 IOSTANDARD LVCMOS18} [get_ports o_la27_p]
set_property -dict {PACKAGE_PIN AR25 IOSTANDARD LVCMOS18} [get_ports o_la26_p]
set_property -dict {PACKAGE_PIN AT25 IOSTANDARD LVCMOS18} [get_ports i_la26_n]
set_property -dict {PACKAGE_PIN AP23 IOSTANDARD LVCMOS18} [get_ports o_la23_n]
set_property -dict {PACKAGE_PIN AN23 IOSTANDARD LVCMOS18} [get_ports o_la23_p]
set_property -dict {PACKAGE_PIN AR24 IOSTANDARD LVCMOS18} [get_ports o_la18_n]
set_property -dict {PACKAGE_PIN AP24 IOSTANDARD LVCMOS18} [get_ports o_la18_p]

#J3
set_property -dict {PACKAGE_PIN AL25 IOSTANDARD LVCMOS18} [get_ports i_la31_n]
set_property -dict {PACKAGE_PIN AK25 IOSTANDARD LVCMOS18} [get_ports o_la31_p]
set_property -dict {PACKAGE_PIN AK22 IOSTANDARD LVCMOS18} [get_ports o_la28_n]
set_property -dict {PACKAGE_PIN AJ22 IOSTANDARD LVCMOS18} [get_ports o_la28_p]
set_property -dict {PACKAGE_PIN AN26 IOSTANDARD LVCMOS18} [get_ports o_la24_n]
set_property -dict {PACKAGE_PIN AM26 IOSTANDARD LVCMOS18} [get_ports i_la24_p]
set_property -dict {PACKAGE_PIN AM23 IOSTANDARD LVCMOS18} [get_ports o_la21_n]
set_property -dict {PACKAGE_PIN AL23 IOSTANDARD LVCMOS18} [get_ports o_la21_p]
set_property -dict {PACKAGE_PIN AU22 IOSTANDARD LVCMOS18} [get_ports o_la22_n]
set_property -dict {PACKAGE_PIN AT22 IOSTANDARD LVCMOS18} [get_ports o_la22_p]
set_property -dict {PACKAGE_PIN AW24 IOSTANDARD LVCMOS18} [get_ports i_la19_n]
set_property -dict {PACKAGE_PIN AV24 IOSTANDARD LVCMOS18} [get_ports o_la19_p]
set_property -dict {PACKAGE_PIN AV23 IOSTANDARD LVCMOS18} [get_ports o_la20_n]
set_property -dict {PACKAGE_PIN AU23 IOSTANDARD LVCMOS18} [get_ports o_la20_p]
set_property -dict {PACKAGE_PIN A28 IOSTANDARD LVCMOS18} [get_ports o_la15_n]
set_property -dict {PACKAGE_PIN B28 IOSTANDARD LVCMOS18} [get_ports i_la15_p]
set_property -dict {PACKAGE_PIN E30 IOSTANDARD LVCMOS18} [get_ports o_la00_n]
set_property -dict {PACKAGE_PIN A29 IOSTANDARD LVCMOS18} [get_ports o_la02_p]
set_property -dict {PACKAGE_PIN A30 IOSTANDARD LVCMOS18} [get_ports o_la02_n]
set_property -dict {PACKAGE_PIN B31 IOSTANDARD LVCMOS18} [get_ports o_la03_n]
set_property -dict {PACKAGE_PIN B32 IOSTANDARD LVCMOS18} [get_ports i_la04_p]
set_property -dict {PACKAGE_PIN A32 IOSTANDARD LVCMOS18} [get_ports o_la04_n]
set_property -dict {PACKAGE_PIN D29 IOSTANDARD LVCMOS18} [get_ports o_la08_p]
set_property -dict {PACKAGE_PIN C29 IOSTANDARD LVCMOS18} [get_ports o_la08_n]
set_property -dict {PACKAGE_PIN C30 IOSTANDARD LVCMOS18} [get_ports o_la07_p]
set_property -dict {PACKAGE_PIN C31 IOSTANDARD LVCMOS18} [get_ports i_la07_n]
set_property -dict {PACKAGE_PIN K29 IOSTANDARD LVCMOS18} [get_ports o_la12_p]
set_property -dict {PACKAGE_PIN J29 IOSTANDARD LVCMOS18} [get_ports o_la12_n]
set_property -dict {PACKAGE_PIN L25 IOSTANDARD LVCMOS18} [get_ports o_la11_p]
set_property -dict {PACKAGE_PIN K25 IOSTANDARD LVCMOS18} [get_ports o_la11_n]
set_property -dict {PACKAGE_PIN K26 IOSTANDARD LVCMOS18} [get_ports i_la16_p]
set_property -dict {PACKAGE_PIN J26 IOSTANDARD LVCMOS18} [get_ports o_la16_n]
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

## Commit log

2025-10-11 dc and rf driver
2025-10-15 trace analysis setup
2025-10-16 pcb mezzanine2header
    [mezzanine2header.kicad_pcb, mezzanine2header.kicad_sch, rowAB.kicad_sch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]
2025-10-16 need to debug rf trace
2025-10-20 Create uart_api_dc
2025-10-21 Update uart_api_dc
2025-10-30 0.1ns wns still seems unstable
    [dc.h, rf.h, swashispin_tb.sv]
2025-11-01 fixed rf dac sample format
2025-11-11 verified axil slave regs on board and deleted designs for mini
2025-11-19 dacboard pcb schematics done
    [alchitry_au_header.kicad_sch, alchitry_au_header_header.kicad_sch, dac.kicad_sch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]
2025-11-24 dacboard routing
    [alchitry_au_header.kicad_sch, dac.kicad_sch, dac1-6.kicad_sch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]
2025-11-25 analog side layout
    [dacboard.kicad_pcb, vref.kicad_sch]
2025-11-25 pcb should reroute
    [dacboard.kicad_pcb]
2025-11-26 analog side should be good
    [dacboard.kicad_pcb]
2025-11-26 low noise digital finished
    [dacboard.kicad_pcb, isolator1-6.kicad_sch, isolator19-24.kicad_sch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]
2025-11-26 adding more capacitors to analog side
    [dac1-6.kicad_sch, dac13-18.kicad_sch, dac19-24.kicad_sch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]
2025-11-26 more capacitors
    [dac1-6.kicad_sch, dac13-18.kicad_sch, dac19-24.kicad_sch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]
2025-11-30 finished routing fpga connections
    [alchitry_au_header.kicad_sch, dacboard.kicad_pcb, vref.kicad_sch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]
2025-12-01 got rid of all drc errors
    [alchitry_au_header.kicad_sch, dac1-6.kicad_sch, dac13-18.kicad_sch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]
2025-12-02 dacboard finished
    [alchitry_au_header_header.kicad_sch, dacboard.kicad_pcb, vref.kicad_sch]
2025-12-02 board name and date
    [dacboard.kicad_pcb]
2025-12-03 fixed a parameter bug in spi master
2025-12-03 dacboard au aux ports
    [alchitry_au_header.kicad_sch, dacboard.kicad_pcb]
2025-12-06 redesigned dacboard analog routing
    [dacboard.kicad_pcb]
2025-12-07 fixed mosi miso flip in inner section
    [alchitry_au_header.kicad_sch, dacboard.kicad_pcb]
2025-12-18 fixed some dc_core bugs
    [dc_core.sv]
2025-12-27 assembler working with rtl simulation
2025-12-29 rf assembly halfway done and reorignized things
    [alchitry_au_header.kicad_sch, dac.kicad_sch, dac1-6.kicad_sch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]
2025-12-29 rf assembler
2025-12-30 assembler works
2026-01-04 better dacboard assembly guide
2026-01-07 button and li asm
2026-01-12 button trigger looks fine in simulation
2026-01-13 good on board
2026-01-16 fixed compile time errors
    [dc_core.sv, dcrfli.sv, dcrfli_btn.sv]
2026-01-19 assembly needs to have ctrl registers
2026-02-07 board died and some LUTs/regs possibly damaged
    [dc.c, dc.h, dcrfli.sv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]
2026-02-23 big board adc simulator
2026-02-25 need spi ahead for dc
2026-03-04 li axi dma
2026-03-22 ex in assembler
2026-04-02 major changes to assembler
2026-04-02 fixed li and ex load insns
    [simulator.sv]
2026-05-01 add sticky_arm/marker to all cores, switch all channels to bram_sequencer
    - dc/rf/ex/li: added sticky_arm and marker to insn structs, decode, and core pipeline stages
    - li: marker only propagates through sample stage (not pack/align/buffer/output)
    - bram_sequencer: added o_iters, o_pcmem_depth, o_pc_rd, o_insn_rd readback ports; SEQ_REGS=REG_PER_INSN+11
    - dc/rf/ex/li .sv: replaced sequencer/serial_sequencer with bram_sequencer, added new status ports
    - dc/rf/ex/li .svh: added *_PC_ADDR_WIDTH=4, updated SEQ_REGS formula
    [dc_core.sv]
2026-05-08 added buffer stage to rf core
2026-05-09 removed button and added squish read
2026-05-11 started new dacboard
    [alchitry_au_header.kicad_sch, dac.kicad_sch, dac1-6.kicad_sch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]
2026-05-12 new pcb progress
    [clk104_board_file.brd, dac1-6.kicad_sch, dac13-18.kicad_sch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]
2026-05-14 finished designing new pcb
    [isolator1-6.kicad_sch, isolator13-18.kicad_sch, isolator7-12.kicad_sch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]
2026-05-15 cleared drc
    [dac1-6.kicad_sch, isolator19-24.kicad_sch, output_header.kicad_sch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]
2026-05-15 fixed dac/adcio headers
    [vita57.4_fmc+.kicad_sch]
2026-05-21 li pipeline: add pc_addr/pc/tag propagation, bram_fifo_2to1, axi_slave_regs
    - Propagate pc_addr and pc through all LI pipeline stages (decode →
    sample → pack → align → buffer → output); expose as o_pc_addr/o_pc
    on li and o_li_tagx4_bus on processor
    - Add sample index and tag (pc_addr+index) generation in li_sample/li_core
    - New bram_2to1 and bram_fifo_2to1: asymmetric 2:1 FIFO using two
    symmetric bram instances for reliable BRAM inference
    - li_save: replace bram_fifo with bram_fifo_2to1, interleave tag+IQ data
    - axi_slave_regs: strict AXI4 verification slave with random backpressure
    and SVA protocol compliance checks
    - simulator: wire o_li_tagx4_bus, i_tagx4 to li_save, add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
2026-06-10 deleted uart functionalities in asm
